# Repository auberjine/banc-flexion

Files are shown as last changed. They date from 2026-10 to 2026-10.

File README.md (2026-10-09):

# Banc de flexion 3 points auto-reactif

Poutrelle beton non arme 103 x 107 x 840, portee 750, capacite 12 kN, pour
fissuration controlee en etuve avec fibre optique et correlation d'images.

Cadre 960 x 440 x 76 mm (flancs), 35,2 kg. Flancs et platines de butee en tole
de 8 mm 42CrMo4 recuit +A, commandee avec certificat 3.1 et Re >= 430 MPa ;
pieds, crochets, plaques de traverse et plateaux du poussoir en tole de 8 mm
S355JR du commerce (seul le flanc a besoin du 42CrMo4). Tout est parametrique : une cote
se change dans `params.py`, et `make.py` refait le 3D, les DXF, les plans et la
notice. Indice B du 05/10/2026.

## Ce qu'il y a dans `out/`

| dossier | contenu |
|---|---|
| `banc_3d.html` | visionneuse 3D autonome, double-clic, aucune installation |
| `fcstd/banc.FCStd` | assemblage FreeCAD, une piece par objet |
| `step/*.step` | geometrie exacte, une piece par fichier, plus l'assemblage |
| `stl/*.stl` | maillages ; `*_montes.stl` contient tous les exemplaires places |
| `dxf/*.dxf` | profils de DECOUPE, contours fermes, arcs exacts ; la traverse y est au brut (surepaisseur a fraiser) |
| `dxf/tole_*.dxf` | tous les exemplaires d'une epaisseur et d'une nuance, ranges en etageres de 3000 mm de large au plus : controle de quantites, pas une imbrication |
| `dxf/*_EN_ATTENTE.dxf` | pieces a NE PAS decouper encore, si `ETUVE_CONFIRMEE` est faux (aucune depuis le 05/10/2026 : largeur de 538 confirmee) |
| `dxf/LISTE.txt` | fichiers, epaisseur, nuance, quantite et statut ; signification des calques |
| `plans/*.svg` | une feuille A3 cotee PAR PIECE fabriquee (`<repere>_<piece>.svg`, cartouche a son repere), plus l'ensemble (00) et le montage de la chape (07m) |
| `plans/plans.pdf` | les memes feuilles en un seul PDF, dans l'ordre des reperes |
| `plans/pdf/*.pdf` | un PDF par feuille, au nom de la feuille (`pdf_feuilles.py`, lance par `make.py`) |
| `masses.json` | masse, volume, matiere et brut de chaque piece |
| `fem_flanc.json` | resultat du calcul elements finis du flanc |
| `flambement3.json` | flambement hors plan, mode symetrique (le facteur a retenir) |
| `iso.json` | projection isometrique de l'assemblage, utilisee par les plans |

`export_dxf.py` vide `out/dxf` avant d'exporter et `build_freecad.py` vide
`out/step` et `out/stl` : aucun fichier d'une generation precedente n'y survit.

Les documents de tete sont `SPEC.md` (engendre, ne pas editer a la main),
`NOMENCLATURE.md` (engendree : commande, visserie, ordre de montage, changement
d'eprouvette) et `DEBOUT.md` (acces a la vis en position verticale et ce que
cette position impose). `SUITE.md` est un HISTORIQUE : la revue du 11/09 et la
suite qui lui a ete donnee.

## Reconstruire

```
python make.py
```

Enchaine le controle des cotes et des ligaments de percage, le modele 3D
FreeCAD (STEP, STL, masses, projection), les DXF, les plans et leur controle de
lisibilite, le PDF des planches, la visionneuse, la nomenclature, la
specification et le controle d'interference ; il termine par le nombre
d'etapes en echec, qui doit etre 0. Il faut Python 3 avec Pillow et openpyxl, FreeCAD 1.0
(`freecadcmd`) et un navigateur Chromium sans interface (Edge, Chrome ou
Chromium) pour le PDF. `outils.py` les trouve, sous Windows comme sous Linux :
variable d'environnement `BANC_FREECAD`, `BANC_CCX` ou `BANC_NAVIGATEUR`
d'abord, puis l'emplacement Windows habituel, puis le PATH.

Avant de lancer une decoupe : mesurer SEPAREMENT les deux toles livrees,
regler `EP_TOLE_REELLE_42` (42CrMo4) et `EP_TOLE_REELLE_S355` (S355JR) dans
`params.py` et regenerer les DXF. Chaque decoupe suit la tole qu'elle RECOIT :
S355 pour les encoches a mi-bois et la mortaise de traverse du flanc et les
fentes de calage du pied ; 42CrMo4 pour les encoches et nodes du pied et les
rainures des patins. Le 3D et le calcul restent a la cote nominale.

Pour refaire seulement les plans et leur PDF (make.py le fait deja) :

```
python plans.py
"C:/Program Files (x86)/Microsoft/Edge/Application/msedge.exe" --headless --no-pdf-header-footer --print-to-pdf=out/plans/plans.pdf out/plans/plans.html
```

Sous Linux : `chromium --headless --no-sandbox --no-pdf-header-footer
--print-to-pdf=out/plans/plans.pdf out/plans/plans.html`. Pour relire les
planches a l'oeil, `python rendu_planches.py` les rend en PNG dans `out/rendus/`.

Pour le calcul elements finis, en deux temps parce qu'il dure plusieurs minutes :

```
freecadcmd fem_flanc.py        (sous Windows : "C:/Program Files/FreeCAD 1.0/bin/freecadcmd.exe")
python fem_run.py
```

Le premier maille et ecrit le fichier CalculiX, le second y injecte la charge
nodale, lance le solveur et depouille le `.frd`.

## Les fichiers source

| fichier | role |
|---|---|
| `params.py` | toutes les cotes, la loi des rondelles Belleville, les calculs (Hertz, coin, filet, platines, tenons, boulonnerie) et les verifications |
| `geom2d.py` | geometrie 2D : contours, conges, bossages, gorges, lumieres |
| `parts.py` | profil de chaque piece et nomenclature du modele : matiere, brut, notes d'operations, pieces du commerce |
| `build_freecad.py` | construction 3D, exports STEP / STL, masses |
| `export_dxf.py` | DXF de decoupe, sans FreeCAD : la liste des pieces plates vient de `parts.all_parts()`, les pieces du commerce n'en ont pas |
| `dxf.py` | ecriture DXF R12 |
| `draw.py` | primitives de dessin technique : vues, cotes, cartouche (indice et date) |
| `plans.py` | les feuilles de plan, une par piece ; `draw.Sheet.fin_piece()` recentre chaque dessin au-dessus des notes |
| `viewer3d.py` | visionneuse 3D autonome : maillages ET three.js (`vendor/three.min.js`, r160) embarques dans `out/banc_3d.html`, qui s ouvre sans reseau |
| `spec.py` | engendre `SPEC.md` depuis le modele |
| `nomenclature.py` | engendre `NOMENCLATURE.md` |
| `nomenclature_xlsx.py` | engendre `out/NOMENCLATURE.xlsx` depuis `NOMENCLATURE.md` (un onglet par tableau, montage ; masses totales en formules) |
| `fem_flanc.py`, `fem_run.py` | calcul elements finis du flanc |
| `fem_balayage.py` | balaye un parametre par le calcul EF (remaille, resout, restaure) ; resultat dans `out/balayage_<param>.json` |
| | `fem_run` refuse un `.inp` deja charge, et ne charge que l arete DROITE |
| | maille de 4,5 mm : a 6 mm l angle d appui variait de 149 a 164 MPa d un calcul a l autre ; a 4,5 mm il converge aux deux appuis. `BANC_MAILLE=<mm>` impose une autre taille sans toucher au fichier |
| | le mode rigide en x est bloque sur UN SOMMET : bloquer une face epingle tous ses noeuds et raidit la tole (197 puis 145 MPa d artefacts au bord de la face) |
| | tole de 8 mm en 42CrMo4 recuit (Re 430, 390 a chaud) : flanc a 213 MPa a l appui (187 a l autre appui de cette piece symetrique : bruit de maillage), 2,02 a froid et 1,83 a 150 C, contre 1,91 a chaud pour le 10 mm S355 ; cadre de 35,2 kg au lieu de 44,5 ; repli EP_FLANC = 10 en S355 ou S460 |
| `fem_flambement.py` | flambement hors plan du flanc (CalculiX *BUCKLE, maille 9 mm), bornes : diaphragmes seuls (pieds, poutrelle ; les tubes negliges) et tubes tenus en z (mode antisymetrique, 31,9 le 18/09, avant les entretoises de chape et de sommet). `--seul x:z ...` essaie des appuis supplementaires |
| `fem_flamb3.py` | le facteur A RETENIR : mode symetrique (les deux flancs penchent ensemble), chaque tube est un ressort de rotation 6EI/L sur sa couronne serree. 13,7 couche avec les six entretoises d'origine, 33,1 avec les deux de chape, 39,0 couche et 39,1 debout avec celle du sommet (9 en tout) ; 38,2 / 38,3 avec les tubes 20 x 2 retenus le 06/10. Une plaque de 600 au dessus ne le porte qu'a 41,9 : inutile |
| `verif_interference.py` | controle d interference sur l assemblage, et des CONTACTS obligatoires |
| `verif_percages.py` | ligaments : chaque percage face aux autres et au contour ; largeur des fentes et des encoches ouvertes du contour |
| `verif_plans.py` | planches : textes superposes, hors feuille ou traverses par un trait (traits fins compris, boite orientee) ; chaque piece nommee sur une planche |
| `pdf_feuilles.py` | decoupe `plans.pdf` en un PDF par feuille dans `out/plans/pdf/` (pypdf) |
| `rendu_planches.py` | rend les planches en PNG (`out/rendus/`) pour les relire a l'oeil |
| `outils.py` | chemins des outils externes (FreeCAD, CalculiX, navigateur), Windows et Linux ; empreinte du modele et date des resultats |

`params.py` porte une fonction `verifie()` qui controle l'empilement vertical,
la course de la pile et du coin, la butee, le contact de Hertz, la place du
bossage sous le patin, la tete de charge, la chape, la boulonnerie M10 (ecrou
sur le filet, bout qui depasse), les bruts d'usinage et l'etuve (douille, pieds,
crochets). `python params.py` l'execute et affiche le bilan.

## Points de conception a ne pas defaire

- **Les flancs sont rentres sous les plats colles.** C'est ce qui degage
  entierement la face laterale de la poutrelle pour la camera. Un flanc au ras
  de la face ne porterait rien.
- **Le contact a lieu au fond de la rainure du patin**, 1,5 mm au dessus de sa
  face inferieure. Tout l'empilement en decoule.
- **Le bossage est un balancier, pas un galet.** Il laisse tourner la poutrelle
  mais n'absorbe pas le recul de 0,06 mm de la fibre basse, qui passe en
  frottement.
- **Le bossage ne porte que sur 6,4 mm** : l'epaisseur du flanc moins ses deux
  aretes cassees. Hertz y vaut 339 MPa, a comparer a 1,6 Re a chaud du corps le
  plus mou, le patin S355JR (480 MPa) : coefficient 1,42.
- **Le bas de la lumiere est une butee de course.** Il interdit d'ecraser la
  pile a plat et plafonne l'effort a 14,4 kN.
- **Le conge R22 au raccordement membrure basse / montant n'est pas le
  levier.** Le point chaud est dans la membrure basse sous le montant, pas sur
  l'arc : un balayage EF de R10 a R26 (16/09/2026, sur le flanc de 10 mm S355
  de l'epoque) donne 151 a 160 MPa sans tendance, du bruit de maillage.
- **Les patins se collent en place**, cadre monte, sous 0,5 kN de precharge.
  C'est l'epoxy qui rattrape l'hyperstaticite des quatre contacts. Colle sur la
  face superieure seulement : la rainure reste seche sur le bossage, qui doit
  basculer. Patins, plats et patin de charge partent avec la poutrelle : un jeu
  par eprouvette.
- **La vis de commande ne bouge pas.** Vis H M16 x 160 ISO 4017 filetee
  jusqu'a la tete : elle tourne en place, retenue axialement dans la chape, et
  c'est le coin qui porte le taraudage et avance. Sa tete reste donc toujours a
  y 137,5, ou une douille l'atteint. Une douille seulement : les bouts des vis
  de chape, a y 160, arretent une cle plate.
- **La commande est normale aux flancs.** Un coin d'acier C45 a 12 degres,
  garni de deux plaques de bronze usinees, coulisse entre le dessous PLAT de
  la traverse et le dessus incline du coulisseau. Le sens des faces est
  essentiel : c'est lui qui fait que le coin ne se deplace que selon y et que
  l'axe de la vis reste fixe. Voir `DEBOUT.md`.
- **Le noeud fait 65 mm de demi-largeur** et porte quatre ouvertures : la fente
  du coin au centre, les deux lumieres de guidage a x = +/- 44 et, plus haut,
  la mortaise de traverse ; les deux trous
  des vis de chape sont au dessus, a x = +/- 52. C'est la zone la plus
  sollicitee apres les appuis. Ne pas y ajouter d'ouverture : il reste 14 mm de
  ligament du cote du bord du noeud et 15 du cote de la fente.
- **Le coin est au repos bout mince affleurant le coulisseau, pas centre.**
  C'est la seule position qui garde le contact sur toute la largeur du
  coulisseau d'un bout a l'autre de la course. Le centrer ferait glisser le
  coin a moitie dehors en fin de course, et la tete basculerait sur la pile.
  C'est aussi ce qui fixe la profondeur de la chape. Voir `DEBOUT.md`.
- **Le dessus du coulisseau est incline sur TOUTE sa section.** La piece fait
  donc 36,2 de haut et non 30 : 30 est l'epaisseur au milieu. Les bruts du
  coulisseau et du coin se calculent sur la boite englobante de la piece finie
  (`parts.bruts_usinage`).
- **Le bout EPAIS du coin est du cote oppose a la chape.** Le coin avance donc
  vers elle en chargeant. La face inclinee le repousse vers son bout epais : le
  filet tire la tige vers l'INTERIEUR du cadre, et sa tete appuie sur la FACE
  EXTERIEURE des platines, a travers deux rondelles trempees. Monte a
  l'envers, la tige serait tiree hors de son alesage et ne pousserait rien :
  c'est le seul sens qui marche, et `verifie()` le controle.
- **Le jeu en largeur de la mortaise vaut DEUX FOIS le rayon de ses conges.**
  L'arete portante droite fait alors exactement la largeur du paquet de tenons.
  Le paquet cumule six fois la tolerance d'epaisseur de tole : la mortaise est
  taillee sur la tole S355 mesuree des plaques (`EP_TOLE_REELLE_S355`), pas sur
  la cote nominale.
- **Les coins de la mortaise sont des CONGES, pas des degagements d'angle.** Un
  os de chien ne se justifie que si la piece conjuguee doit porter dans l'angle.
  Ici le paquet a 2 mm de jeu par cote, et le degagement creusait une entaille
  au bout de la ligne d'appui : 209 MPa au calcul EF contre 130 (flanc de 10).
- **Les pieds de tenon portent un DEGAGEMENT, jamais un conge** -- traverse
  comme coulisseau. Un conge a un angle rentrant ajoute de la matiere dans
  l'angle : il deborde de l'epaulement et vient mordre la face du flanc.
  `geom2d.relief_ll()` fait cela, `Contour.add(..., relief=True)` l'appelle.
- **`COULISSEAU_E` n'est PAS `POUSSOIR_H`.** Depuis que le poussoir est un
  empilage de tole, ce sont deux cotes sans rapport. Les confondre dans
  `f_coulisseau` a laisse 5,9 mm de jeu entre le coin et le coulisseau pendant
  deux versions : la chaine d'effort etait ouverte dans le modele et aucun
  controle ne bronchait, un jeu n'etant pas une interference.
- **`verif_interference.py` verifie aussi les CONTACTS obligatoires.** La liste
  `CONTACTS` suit l'effort du coin jusqu'aux appuis ; c'est elle qui garantit
  que la chaine est fermee. Y ajouter tout nouveau maillon.
- **L'epaisseur du coulisseau ne tient pas a la contrainte** (5,2 MPa de
  compression pure) mais a deux details : 5 mm de matiere au dessus des
  taraudages de guide du cote MINCE de la pente, et un chapeau au dessus de
  l'alesage du tourillon. `verifie()` controle les deux.
- **La graduation de charge se lit sur le HAUT DE TETE de guide**, pas sur le
  dessus du coulisseau, invisible entre les flancs. La tangente superieure du
  cylindre se lit comme une bulle de niveau. Elle n'est gravee que d'un cote de
  la lumiere : face gravee de chaque flanc montee a l'exterieur.
- **Le coulisseau est guide par les TETES de quatre CHC M8 x 12 ISO 4762**,
  tete lisse, vissees apres coup au travers des lumieres. Un cylindre sur un
  plan porte sur une ligne : il ne peut pas se coincer en biais et il encaisse
  les defauts angulaires. Ne pas revenir a des tenons prismatiques, et ne pas
  mettre de vis a tete fraisee.
- **La tete de CHC M8 fait 13 x 8** : le 8 est exactement l'epaisseur du
  flanc. C'est ce qui rend le montage possible, `verifie()` le controle. La
  longueur d'une CHC se compte SOUS la tete : les 12 mm entrent tout entiers
  dans le taraudage de 16. Une x 20 y talonnait et laissait la tete hors de sa
  face.
- **On visse les guides APRES avoir ferme le cadre.** C'est tout l'interet :
  plus de tenons a engager a l'aveugle en presentant le second flanc.
- **Le chant du bas des plaques de traverse se fraise EN PAQUET**, plaques
  serrees sur leur tirant et alignees sur les faces hautes des tenons. C'est le
  plan de glissement du coin : une plaque en saillie de 0,1 mm deviendrait une
  charge lineique sur le bronze. Le DXF porte 1 mm de surepaisseur sur ce chant.
- **Les pieces de tole n'ont AUCUN chanfrein au modele** (09/10/2026) :
  aretes ebavurees seulement. Un STEP a aretes vives passe mieux dans les
  analyseurs des sites de decoupe. Les calculs gardent 0,8 non portant a
  chaque bord (`CHANFREIN`) : bossage, plaque de bronze sous la traverse,
  tenons.
- **Les trois plateaux du poussoir sont PERCES** : c'est le patin de charge
  colle qui fait fond sous le tourillon. `verifie()` exige ALESAGE_P == POUSSOIR_H.
  Ils sont serres en un bloc par deux vis H M6 x 35, TETE EN DESSOUS : sous le
  plateau bas il n'y a que les 10 du patin au sommet du bombe jusqu'a la
  poutrelle, une tete de 4 y tient, un ecrou non. Le patin de charge, sans
  trou, est raccourci selon x (PATIN_CHARGE_L, tire de POUSSOIR_VIS_X) pour
  laisser passer les tetes ; `controle_vis_poussoir()` en verifie les gardes.
  Le bloc n'est pas localise sur le patin : le tourillon le centre.
- **La butee de vis est POUSSEE, pas tiree.** C'est une consequence du sens de
  montage du coin, et c'est ce qui permet de la faire en tole : deux platines
  de 8 sur deux entretoises tubulaires, en compression. Si l'on remontait le
  coin a l'envers, il faudrait revenir a une chape usinee.
- **Ecrous autofreines TOUT METAL (ISO 7042)** sur la visserie M10 du cadre :
  une bague polyamide flue vers 120 C et ne freine plus dans l'etuve. Toutes
  les longueurs de vis sont controlees par `verifie()` (`params.boulonnerie`).
- **`verif_percages.py` fait partie de `make.py`.** Il refuse tout ligament
  inferieur a 0,8 fois l'epaisseur, et toute fente ou encoche du contour plus
  etroite que la demi-epaisseur. C'est lui qui a trouve l'entretoise de coin
  centree sur l'arete du flanc et l'ajour qui recoupait un trou de pied.

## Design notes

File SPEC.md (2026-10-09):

# Banc de flexion 3 points - specification

Indice B du 05/10/2026. Fichier engendre par `spec.py` a partir de `params.py`,
du calcul elements finis et du modele 3D. Ne pas le modifier a la main.

## 1. Objet

Fissuration controlee d'une poutrelle beton non arme instrumentee fibre
optique, en etuve jusqu'a 150 degres C, avec correlation d'images sur une
face laterale. Le cadre est auto-reactif : aucune reaction exterieure. Il
travaille COUCHE sur la paillasse et DEBOUT, sur son about, dans l'etuve
(voir `DEBOUT.md`).

## 2. Eprouvette et renfort

| grandeur | valeur |
|---|---|
| Poutrelle | 103 x 107 x 840 mm, beton non arme |
| Plats de renfort colles | 2 x 20 x 2 x 840, feuillard S235 du commerce, a y = +/- 34 (axe des flancs) |
| Colle | epoxy haute temperature (Duralco 4420) |
| Axe neutre de la section homogeneisee | 50.86 mm au dessus de la face inferieure |
| Inertie homogeneisee | 1.21e+07 mm4 |
| Effort a la fissuration (beton a 4 MPa) | 5.07 kN |
| Fleche a la fissuration | 0.123 mm |

Le renfort rend la fissuration progressive et pilote l'ouverture. Il
descend l'axe neutre de 2.6 mm par rapport au beton nu.

Les deux plats, les quatre patins d'appui et le patin de charge sont colles
sur la poutrelle et partent avec elle : il en faut un jeu par eprouvette.

## 3. Chargement

| grandeur | valeur |
|---|---|
| Schema | 3 points, portee 750 mm |
| Charge de dimensionnement du cadre | 12 kN |
| Commande | coin d'acier C45 a 12 deg garni de deux plaques de bronze usinees, vis H M16 pas 2.0 filetee jusqu a la tete, normale aux flancs |
| Pile de rondelles | 12 x EN 16983 A50 (ex-DIN 2093) en 51CrV4 (1.8159) (50 x 25.4 x 3.0), montees tete-beche |
| Hauteur libre de la pile | 51.6 mm |
| Effort de la pile a plat | 18.5 kN |
| Course totale | 15.6 mm |
| Ecrasement a 12 kN | 9.65 mm (raideur secante 1243 N/mm) |
| Butee de course en bas de lumiere | 11.8 mm, plafonne l'effort a 14.4 kN |
| Rattrapage d'empilement | 2.4 mm de course en reserve au dela des 12 kN (2 exiges) ; cales de 1 et 2 mm, D50 / D26, entre poussoir et pile |
| Precharge de collage, 0,5 kN | 0.36 mm de pile, 1.68 mm de coin, 0.84 tour de vis apres le contact |

La loi des rondelles Belleville n'est pas lineaire. Graduation gravee :

| charge | descente du coulisseau |
|---|---|
| 2 kN | 1.45 mm |
| 4 kN | 2.97 mm |
| 6 kN | 4.55 mm |
| 8 kN | 6.19 mm |
| 10 kN | 7.89 mm |
| 12 kN | 9.65 mm |

Cette lecture est un indicateur a quelques pour cent pres : elle englobe la
souplesse propre du cadre (0.335 mm a 12 kN) et la fleche de la poutre.
La mesure de reference est la fibre collee sur la membrure haute.

## 4. Appuis

Les flancs sont RENTRES sous les plats de renfort : ils portent dessous, et
la face laterale de la poutrelle reste entierement degagee pour la camera.

| poste | cote |
|---|---|
| Largeur de la poutrelle | 103 |
| Debord de la poutrelle de chaque cote | 13.5 |
| Epaisseur d'un flanc | 8 |
| Ecart interieur entre flancs | 60 (impose par les rondelles 50) |
| Largeur hors tout des flancs | 76 |
| Face inferieure libre au centre | 48 (passage du cable) |

Le contact se fait au FOND de la rainure du patin, 1.5 mm au dessus de sa
face inferieure.

| grandeur | valeur |
|---|---|
| Patins d'appui | 90 x 20 x 10, S355JR, colles en place |
| Rainure de guidage | 9.5 x 1.5, fraisee apres decoupe, jeu 0.75 par cote sur la tole reelle du flanc (EP_TOLE_REELLE_42) |
| Bossage | R150, relief 3.5, largeur totale 66.6 |
| Pression de Hertz a 12 kN | 339 MPa sur 6.4 mm portants (flanc de 8 moins 0.8 a chaque bord, ebavure, non compte) |
| Limite au contact a 150 degres C | 480 MPa, 1,6 Re a chaud du corps le plus mou (le patin S355JR) ; coefficient 1.42 |
| Pression sur le beton sous un patin | 1.67 MPa |
| Bras contact - axe neutre | 61.36 mm |

Le bossage est un BALANCIER, pas un galet. Il donne une ligne de contact
nette et laisse tourner la poutrelle, mais il n'absorbe pas le recul de
0.060 mm de la fibre basse a la fissuration, qui passe en frottement et
coute quelques pour cent sur le moment. Pour le supprimer il faudrait un
vrai galet libre sur une des deux lignes d'appui.

Les patins sont colles sur le plat par leur face SUPERIEURE seulement : la
rainure reste seche sur le bossage, qui doit pouvoir basculer.

## 5. Empilement vertical

z = 0 au bord inferieur du flanc.

| z | element |
|---|---|
| 40.0 | dessus de la membrure basse |
| 42.0 | dessous du patin d'appui |
| 43.5 | sommet du bossage, fond de rainure, point de contact |
| 52.0 | dessous du plat de renfort |
| 54.0 | face inferieure de la poutrelle |
| 161.0 | face superieure de la poutrelle |
| 171.0 | dessus du patin de charge |
| 195.0 | dessus du poussoir |
| 246.6 | dessous du coulisseau, pile libre |
| 236.9 | dessous du coulisseau a 12 kN |
| 276.6 | dessus du coulisseau, pile libre |
| 325.7 | dessous de la traverse a tenons, plan de glissement du coin |
| 420.0 | dessous de la membrure haute |
| 440.0 | hors tout |

Encombrement des flancs 960 x 440 x 76 mm. Selon y, le banc va de -85.5
(coin recule) a +160 (bout des vis de chape), soit 245.5 mm ; les pieds font 518.4.
Etuve 538 x 528.4 x 1400 mm (largeur x profondeur x hauteur ; largeur confirmee, profondeur = pieds + 5 de chaque cote, hauteur a confirmer) : le cadre y travaille DEBOUT sur son
about, pose par deux pieds en V sur quatre crochets pendus aux parois ; sur
la paillasse il travaille couche sur deux pieds. Voir `DEBOUT.md`.

## 6. Flanc en treillis

Le moment est triangulaire et la profondeur du treillis suit, donc l'effort
dans la membrure haute est constant sur toute sa longueur.

| membre | section | valeur |
|---|---|---|
| Membrure haute | 20 x 8 | 7.58 kN de traction, 47.4 MPa |
| Bielles | 35 x 8, pente 17.97 degres | compression |
| Montants | 45 x 8 | traction |
| Membrure basse | 40 x 8 | moment constant de 180 N.m entre appuis |
| Profondeur du treillis | 148.4 mm | |

Calcul elements finis CalculiX, 259107 noeuds, elements du second ordre,
charge de 6000 N au noeud, appuis glissants sur les deux bossages :

| grandeur | valeur |
|---|---|
| von Mises maxi | 213 MPa |
| Coefficient a froid, 42CrMo4 +A (Re 430) | 2.02 |
| Coefficient a 150 degres C (Re 390) | 1.83 |
| Fleche du flanc | 0.335 mm |
| Flambement hors plan, mode symetrique (fem_flamb3, 05/10/2026) | facteur 38.2 couche, 38.3 debout, avec les 9 entretoises |
| Flambement, flancs en sens contraire (fem_flambement, 18/09/2026) | facteur 31.9 au moins : calcul fait avant les entretoises de chape et de sommet, qui ne peuvent que le relever |

Points les plus charges :

| x | z | von Mises | zone |
|---|---|---|---|
| -420 | 30 | 213 MPa | membrure basse sous le montant, cote appui ; encoche de pied du coin voisine |
| 420 | 30 | 187 MPa | membrure basse sous le montant, cote appui ; encoche de pied du coin voisine |
| -30 | 390 | 187 MPa | angle de la mortaise de traverse, arete ou portent les tenons |
| -390 | 30 | 130 MPa | console d'appui sous le bossage |
| 390 | 30 | 125 MPa | console d'appui sous le bossage |
| 30 | 270 | 103 MPa | ligament entre la fente du coin et la lumiere |
| -30 | 270 | 103 MPa | ligament entre la fente du coin et la lumiere |
| -60 | 240 | 90 MPa | angle bas du noeud |

La piece est symetrique, le calcul donne pourtant 213 MPa d'un cote et 187
de l'autre : c'est l'ordre de grandeur du bruit de maillage a l'appui, et
l'on retient la plus forte valeur.

Le point chaud est dans la membrure basse sous le montant, pas sur l'arc
du conge R22 du raccordement membrure basse / montant.
Un balayage du rayon de R10 a R26 (fem_balayage.py, 16/09/2026, sur le flanc de
l'epoque) donne 151 a 160 MPa sans tendance : c'est du bruit de maillage,
le rayon n'est pas le levier.

NUANCE ET EPAISSEUR. Le flanc est en tole de 8 mm 42CrMo4, etat recuit +A
(Re 430, 390 a 150 C). L'EN 10083-3 ne garantit a l'etat +A qu'une durete
maximale, pas de limite elastique : toute la marge du flanc repose sur Re,
qui est donc EXIGE a la commande -- 42CrMo4 recuit +A, tole 8 mm : certificat 3.1 EN 10204 avec essai de traction, Re >= 430 MPa a 20 C.
Le flanc travaille a 213 MPa a l'appui : 2.02 de coefficient a froid, 1.83 a
150 C, contre 1,91 a chaud pour le cadre precedent en 10 mm S355 (157 MPa)
et 34.5 kg de cadre au lieu de 44,5.
Si la tole de 8 en 42CrMo4 manque, le repli est le 10 mm S355 ou S460 :
EP_FLANC = 10 et tout suit.

DEUX TOLES DE 8 (decision du 05/10/2026). Seul le flanc a besoin du 42CrMo4 :

| piece | nuance | pourquoi |
|---|---|---|
| Flanc | 42CrMo4 +A, tole 8 mm, cert. 3.1, Re >= 430 | 213 MPa a l'EF : toute la marge du cadre |
| Platine de butee | 42CrMo4 +A, tole 8 mm, cert. 3.1, Re >= 430 | 130 MPa : en S355JR elle n'aurait plus que 2.3 a 150 C, sous le seuil de 2,5 de `verifie()` ; imbriquee dans les chutes de la tole des flancs |
| Plaques de traverse | S355JR, tole 8 mm, cert. 2.2 | 8 MPa en flexion, 26 au matage ; chant fraise frottant sur la plaque bronze-graphite, acceptable a 8 MPa et a cette vitesse |
| Crochets, pieds, plateaux du poussoir | S355JR, tole 8 mm, cert. 2.2 | une quinzaine de MPa au crochet, quelques MPa ailleurs |

Les deux toles se mesurent SEPAREMENT (EP_TOLE_REELLE_42, EP_TOLE_REELLE_S355) :
chaque fente, encoche ou mortaise suit la tole qu'elle RECOIT (voir le
paragraphe des points ouverts).

## 7. Tete de charge

Chaine d'effort, de haut en bas : traverse a tenons portee par la mortaise
des flancs, coin de commande qui glisse sous elle sur ses plaques de bronze,
coulisseau guide par les tetes de quatre CHC M8 dans les lumieres, pile de
rondelles sur tourillon colle dans le coulisseau, poussoir, patin de charge colle. La
reaction remonte par les montants et les bielles dans la membrure haute,
qui travaille en traction.

| piece | remarque |
|---|---|
| Traverse | 6 plaques de tole 8, tenons dans la mortaise des flancs, chant du bas fraise en paquet |
| Coulisseau | S355JR, dessus incline sur TOUTE sa section ; un bloc, sans tenon |
| Guidage | 4 tetes de CHC M8 x 12 ISO 4762, tete lisse, diametre 13, dans des lumieres de 14 ; taraudages M8 prof. 16 |
| Poussoir | 3 plateaux de tole 8 perces, serres en un bloc par 2 vis H M6 x 35 ISO 4017 8.8 a +/- 38, tete en dessous, rondelle et ecrou ISO 7042 au dessus, 8 N.m ; le patin de charge fait fond |
| Vis du poussoir, tete en dessous | sous le plateau bas il n'y a que les 10 du patin au sommet du bombe jusqu'a la poutrelle : un ecrou, sa rondelle et le bout de vis n'y tiennent pas, une tete de 4 si (6 de garde) ; angle de tete a 3.5 du bout du patin, angle d'ecrou a 7.5 de la pile |
| Patin de charge | dessus BOMBE R1000 (0.42 de chute aux bords), dessous plat colle : le poussoir porte sur une ligne transversale, Hertz 88 MPa a 12 kN, coefficient 5.4 |
| Alignement du poussoir | les 3 plateaux sont visses en bloc ; le bloc n'est pas localise sur le patin : c'est le tourillon, colle dans le coulisseau, qui le centre (jeu 0.4 dans l'alesage 25.4 des plateaux), et le patin de charge est colle centre au trace |
| Patin de charge, encombrement | 58 x 100 x 10 sans trou : sa longueur selon x laisse passer les tetes des vis du poussoir ; 2.07 MPa sur le beton a 12 kN |
| Tourillon | C45+C, rond etire 25 h9 x 79.5 non repris, COLLE au fond du coulisseau (Loctite 648 (tient 175 C), alesage 25 H8 degraisse) ; dans le poussoir : 7.9 au repos, 4.9 avec les cales, 4.3 de garde au dessus du patin a la butee |
| Vis de commande | vis H M16 x 160 ISO 4017 8.8 brute, filetee jusqu a la tete, immobile axialement dans la chape, le coin est son ecrou |
| Butee de course | bas de la lumiere, interdit l'aplatissement de la pile |

## 7 bis. Commande par coin

L'etuve fait 538 x 528.4 x 1400 (largeur x profondeur x hauteur, largeur confirmee) et n'offre aucun passage de paroi
utilisable. Le cadre y est debout : un axe de vis dans le plan des flancs
regarderait une paroi a 49 mm, inaccessible. La commande est donc NORMALE
AUX FLANCS. Un coin en ACIER, qui porte le taraudage, coulisse selon y entre
le dessous plat de la traverse et le dessus du coulisseau taille au meme
angle. Le coin ne se deplace que selon y : son dessus reste plaque sous la
traverse, donc l'axe de la vis est fixe.

| grandeur | valeur |
|---|---|
| Angle | 12 degres |
| Coin | acier C45, 40 de large, 30.8 a 55.2 d'epaisseur, 114.5 de long |
| Plaques de frottement | 2 plaques usinees en CuSn12-C, 38 x 102 (dessus) et 38 x 104 (dessous) x 6, sous pate graphite haute temperature, 0.41 kg en tout |
| Course utile | 56.5 mm selon y |
| Position de repos | bout epais a y -85.5, bout mince a y 29 |
| Sens de marche | vers la chape ; en fin de course le bout mince est a y 85.5 |
| Depassement hors cadre | 47.5 mm, d'un cote au repos, de l'autre en fin de course |
| Vis | M16 pas 2.0, taraudee dans le coin, immobile axialement |
| Effort moteur a 12 kN | 5.5 kN |
| Couple sur la vis | 14.5 N.m |
| Course par tour | 0.425 mm de coulisseau, environ 549 N |
| Pression de contact, fin de course | 7.6 MPa en haut sur 30.0 x 52.8 (joints de traverse deduits), 6.3 MPa en bas sur 38 x 50.4 ; 25 admis |
| Rendement | 46 pour cent |

Le coin n'est autobloquant que si le frottement de ses deux faces depasse
0.106 (tan a / 2) : avec le bronze graphite a chaud (0.12) on y est a peine,
on ne compte donc pas dessus. C'est la vis M16 qui tient la charge, son
angle d'helice etant tres inferieur a l'angle de frottement. Le filet est
de l'acier sur acier monte a la pate cuivre, et le cas dangereux est le
frottement BAS : a 0.08, helice 2.48 degres contre 5.28 degres de frottement
apparent, marge x2.13.

C'est pourquoi le filet reste METRIQUE a pas de 2 et non trapezoidal.
Au meme frottement de 0.08, un Tr16x4 tomberait a une marge de 0.91 :
il serait REVERSIBLE, et il doublerait le pas de charge a 1099 N par tour.
A pas egal, le profil trapezoidal ne gagne rien non plus : sa hauteur de
recouvrement vaut 0,5 P contre 0,541 P pour le metrique, soit MOINS de
flanc portant. Les flancs travaillent a 9.2 MPa, engagement plafonne a
1,5 d, pour 12 admis sur un taraudage C45 et une vis 8.8 en manoeuvre lente.

Le filet est TARAUDE DIRECTEMENT DANS L'ACIER du coin. Une bague-ecrou en
bronze a ete dessinee puis abandonnee : a la vitesse de manoeuvre d'un
banc a la main, ce n'est pas la vitesse qui use un filet, et le couple
vis 8.8 sur C45 brut tient sans probleme monte a la pate cuivre. La vis
est la plus dure : c'est le taraudage du coin qui s'use, et il se refait.
Il ne court que sur 80 mm et non sur toute la longueur du coin ; au dela
le percage est repris a 18, si bien que le taraud debouche dans un trou
plus grand : les copeaux s'evacuent vers l'avant et il n'y a que 5 d a
tarauder au lieu de 7. Si le filet devait un jour lacher, le lamage
d'une bague de bronze reste possible : rien ici n'est irreversible.

LE BRONZE N'EST PLUS QUE DEUX PLAQUES, TOUTES DEUX SUR LE COIN.
Un coin de bronze plein aurait demande 2,7 kg de barre, une section qu'il
faut faire debiter. Or le bronze n'est utile que sur les deux faces de
glissement : il est reporte sur deux plaques de frottement en CuSn12-C, de
simples rectangles fraises dans un plat 40 x 8 (38 x 102 et 38 x 104, ep. 6),
usines avec le reste plutot qu'achetes a part, et le coin devient un bloc d'acier C45
de 1.37 kg, usine dans un plat 70 x 45, L 120 (fini 63 x 40 x 114,5).

La basse pourrait etre posee sur la pente du coulisseau, ou elle ne ferait
que 58 de long au lieu de 104. Elle est mise sur le coin comme la
haute : le coulisseau redevient un bloc nu -- un percage et un plan a 12
degres, ni poche ni taraudage -- les deux faces d'usure sortent ensemble
avec le coin, et c'est deux fois le meme rebord a usiner. Ce que cela
coute : la plaquette basse traverse la fente du flanc avec le coin, qui
s'approfondit donc de 6.1 mm.

Aucune vis : le coin ne fait que 40 de large et le percage de la vis en
prend le milieu, il ne reste pas de quoi noyer une tete fraisee a un
ligament d'epaisseur. Chaque plaquette est prise entre DEUX REBORDS usines
dans la masse, 4.25 (dessus) et 4.43 (dessous) x 4, qui encaissent les 1.44 kN
d'entrainement dans l'axe de la vis : flexion 23.9 MPa au pied, matage du chant 18 MPa.
Elles ne sont PAS collees a l epoxy. Bronze et acier ne se dilatent pas
pareil : a 150 C la plaquette s allonge de 0.09 mm de plus que son siege,
et un joint rigide sur toute la longueur encaisserait 30 a 80 MPa de
cisaillement en bout pour 15 a 20 tenus : il fissurerait au premier
chauffage. Les rebords prenant tout l entrainement, la fixation n a plus
qu a tenir la plaquette le temps du montage : quelques points de silicone
haute temperature, 1000 fois plus souple, y suffisent -- 0.146 MPa de
cisaillement thermique dans le joint. Le CuSn12-C n'est pas autolubrifiant :
pate graphite haute temperature sur les faces de glissement, posee APRES la prise du silicone ;
rien sur les sieges, le silicone ne prend pas sur une pate.

Pied de rebord SANS degagement : conge R2, le bout d'une fraise de 4 (pas de
conge interieur sous R2 sur les pieces fraisees),
et chaque logement a 4 de plus que sa plaquette, si bien que l'angle du
bronze ne monte pas sur le conge. Et sur la face inclinee, la face interieure
du rebord est NORMALE A LA PENTE et non verticale, comme le chant de la
plaquette : dessinees verticales, elles la mordaient de 1.3 mm en bas.

Les rebords s'arretent 2 mm SOUS la surface du bronze. Aux deux bouts de
course ils passent sous la conjuguee, et s'ils affleuraient ce serait de
l'acier sur acier qu'on ferait glisser. Il en coute de la portee : la
plaquette haute porte sur 52.8 mm au lieu de 60, la basse sur 50.4 au
lieu de 58, soit 7.6 et 6.3 MPa.

Le filet reste engage sur 27.0 mm coin recule, soit 1.7 d, ce qui est
tout ce qui porte : au dela de 1,5 d, l'ecart de pas entre la vis et le
taraudage fait que les derniers filets ne prennent plus rien.

Le coin traverse les deux flancs par une fente de 44 x 71, entre les
deux lumieres de guidage reportees a x = +/- 44. Il reste alors 58 mm
de section nette dans le noeud, soit 12.9 MPa nominal pour les 6000 N par flanc.

La suppression de la vis verticale a ramene la hauteur du cadre de 480 a
440 mm : debout dans l'etuve de 538, il reste 49 mm de chaque cote, ou se
logent les pieds en V et les crochets. Elle a aussi permis de descendre le
noeud : la profondeur du treillis passe de 139,5 a 148.4 mm.

### Sens de montage du coin, et arret axial de la vis

Le bout EPAIS du coin est du cote OPPOSE a la chape : le coin avance donc
VERS elle en chargeant. C'est ce sens, et lui seul, qui rend l'arret axial
de la vis possible. L'equilibre du coin le montre : la composante selon y
de la reaction du coulisseau, plus les deux frottements, valent 5.5 kN, et
la vis doit les fournir. La face inclinee repousse le coin vers son bout
EPAIS : le filet tire donc la vis vers l'INTERIEUR du cadre, et sa tete
vient appuyer sur la FACE EXTERIEURE des platines, a travers deux rondelles
trempees graissees. Cote interieur, deux autres et deux ecrous minces ne
reprennent que l'effort de desserrage : 329 N a un frottement de 0.12, quand
le coin est autobloquant ; en dessous de 0.106 la charge le chasse d'elle-meme
et ils ne voient rien.

Monte a l'envers, le coin s'eloignerait de la chape en chargeant : la vis
serait tiree hors de son alesage et ne pousserait rien. Il faudrait alors
loger la butee entre les platines et le bout du coin, ou elle ne tient
pas. Le controle des cotes refuse ce sens.

### Position de repos du coin

Le coin est dessine au repos bout mince AFFLEURANT le bord du coulisseau,
et non centre sur lui. C'est la seule position qui garde le contact sur
toute la largeur du coulisseau d'un bout a l'autre de la course. Centre au
repos, le coin aurait glisse a moitie hors du coulisseau en fin de course :
appui reduit a 29 mm au lieu de 58, pression doublee, et surtout
resultante decalee de 14.5 mm, donc basculement de la tete sur la pile.
Le prix a payer est que le bout mince atteint y 85.5 en fin de course, ce
qui fixe la position de la chape de butee.

## 7 ter. Butee axiale de la vis

Le coin avance VERS la butee en chargeant et tire la vis vers l'interieur
du cadre ; la tete de la vis pousse donc la butee, et les platines, contre
le flanc : platines en flexion, entretoises en compression, aucune piece de
la butee ne travaille en traction. Il n'y a aucune raison d'usiner une chape
dans la masse. Deux platines de la MEME tole que les flancs, portees par deux
entretoises du MEME tube que le cadre, de part et d'autre de la vis, dans le
plan de son axe. Deux vis H M10 x 200 traversent platines, entretoises de
butee, LES DEUX flancs et une entretoise de cadre entre eux, tete derriere
le flanc oppose, ecrou cote platines : plus aucun taraudage dans le flanc,
et deux entretoises de plus entre les flancs. Elles ne voient que la
precharge et les 329 N de desserrage.

| grandeur | valeur |
|---|---|
| Platines | 2 x tole 8, 70 de haut au droit de l'alesage, 140 de long |
| Flexion d'une platine | 130 MPa, coefficient 3.3 a froid, 3.0 a 150 C, fleche 0.139 mm |
| Entretoises de butee | tube de precision 20 x 2, L = 71.5 +/-0,2, 24.5 MPa de COMPRESSION chacune |
| Fixation | 2 vis H M10 x 200 ISO 4014 (filetees sur 32) a x = +/- 52, z 303.7, tete et 1 rondelle derriere le flanc oppose, 4 rondelles + 2 ecrous H contre-bloques cote platines |
| Serrage sous tete | 173.5 mm, filet a partir de 168 : ecrou sur le filet avec 5.5 de marge, 9.7 de depassement |
| Serrage | 25 N.m, aucun taraudage : les vis traversent les deux flancs |
| Butee sous la tete | 2 rondelles trempees AS 1730, pate graphite haute temperature entre elles, a plat sur la face EXTERIEURE ; frottement 0.10 compte dans le couple |
| Retenue interieure | 2 rondelles trempees AS 1730 + 2 ecrous HM M16, 18 mm, desserrage seulement |
| Tete de la vis | dessus a y 138, soit 117 mm de degagement pour la douille, cadre decentre au pire dans l'etuve de 528.4 (127 centre) |
| Manoeuvre | douille de 24 et cliquet SEULEMENT : les bouts des vis de chape (y 160) depassent la tete de manoeuvre dans son plan, une cle plate bute dessus |

Tout sort du debit deja commande : les platines nichent dans la tole de 8
des flancs, les entretoises sont coupees dans le meme tube que celles du
cadre. Rien a usiner. Les vis traversent LES DEUX flancs, avec une
entretoise de cadre entre eux : la commande se monte du cote que l'on veut,
en retournant le coin, et les deux percages servent dans les deux cas.

Une entretoise de sommet, dans l'axe a z 412, au dessus de la mortaise de
traverse : la membrure haute n'avait aucune liaison sur 500 mm et c'est la
que partait le mode de voilement symetrique. Meme tube de 60, meme vis TH
M10 x 100 que les autres entretoises de cadre. Ce n'est PAS un serrage des
flancs sur le paquet de traverse : le tube de 60 fixe l'ecart des flancs,
et les epaulements de la traverse gardent 0.4 de jeu selon y (0.2 de chaque
cote) : la traverse n'est jamais pincee.

Boulonnerie M10 du cadre, toutes longueurs controlees par `verifie()` sur la
tole reelle (EP_TOLE_REELLE_42 au travers des flancs et des platines, paquet de
traverse a TRAVERSE_LX_REEL en S355) : l'ecrou doit tomber sur le filet avec 2.5 de
marge et le bout depasser de 3 pour que le freinage soit en prise.

| boulonnerie | serrage | ecrou | depassement | marge de filet |
|---|---|---|---|---|
| vis de cadre TH M10 x 100 | 80.0 | 10 | 10.0 | - |
| vis de traverse H M10 x 100 | 52.0 | 10 | 38.0 | - |
| vis de chape H M10 x 200 | 173.5 | 16.8 | 9.7 | 5.5 |

Ecrous de cadre et de traverse : ISO 7042 classe 8, autofreine tout metal. Pas d'ecrou a bague polyamide
(ISO 7040, DIN 985) : la bague flue vers 120 C et ne freine plus a 150 C.
7 vis de cadre (4 de coin, 2 de bielle, 1 de sommet) et 2 vis de chape
serrent les 9 entretoises.

## 8. Instrumentation

| poste | valeur |
|---|---|
| Fibre sur le chant de la membrure haute | 18.8 microdeformations par kN |
| Resolution a 1 microdeformation | 53 N |
| Lecture mecanique | position du coulisseau dans la lumiere |
| Correlation d'images | face laterale degagee sur 840 x 107 mm |

Il n'y a pas de col de mesure : la membrure pleine donne deja une
resolution suffisante, et un col serait une entaille de plus.

## 9. Masses

Masses du modele 3D (out/masses.json, construit le 09/10/2026).

| piece | qte | masse unitaire | total |
|---|---|---|---|
| Flanc en treillis | 2 | 10.24 kg | 20.48 kg |
| Plaque de traverse | 6 | 0.25 kg | 1.51 kg |
| Plateau de poussoir | 3 | 0.33 kg | 0.98 kg |
| Coulisseau a tete inclinee | 1 | 1.46 kg | 1.46 kg |
| Vis de guidage CHC M8 x 12 | 4 | 0.01 kg | 0.05 kg |
| Tourillon de centrage | 1 | 0.31 kg | 0.31 kg |
| Coin de commande | 1 | 1.37 kg | 1.37 kg |
| Plaque de frottement, dessus | 1 | 0.20 kg | 0.20 kg |
| Plaque de frottement, dessous | 1 | 0.21 kg | 0.21 kg |
| Vis de commande H M16 x 160 | 1 | 0.34 kg | 0.34 kg |
| Platine de butee de la vis | 2 | 0.45 kg | 0.91 kg |
| Entretoise de butee | 2 | 0.06 kg | 0.13 kg |
| Patin d'appui rainure | 4 | 0.13 kg | 0.52 kg |
| Patin de charge | 1 | 0.45 kg | 0.45 kg |
| Plat de renfort colle | 2 | 0.26 kg | 0.53 kg |
| Entretoise tubulaire | 9 | 0.05 kg | 0.48 kg |
| Pied a mi-bois | 4 | 0.87 kg | 3.49 kg |
| Crochet d etuve | 4 | 0.17 kg | 0.69 kg |
| Pile de 12 rondelles Belleville | 1 | 0.41 kg | 0.41 kg |
| Poutrelle beton | 1 | 22.22 kg | 22.22 kg |

**Cadre complet 34.5 kg**, poutrelle 22.2 kg.

## 10. Conduite d'essai

- rampes thermiques sous 0,2 degres C par minute : avec 107 mm d'epaisseur,
  une rampe de 1 degre par minute creee deja 5 MPa d'ecart entre coeur et peau
- palier de stabilisation d'au moins 2 heures avant toute lecture
- acier nu ou phosphate, pas de zingue au dela de 200 degres C
- pate graphite ou cuivre sur le filetage de la vis, pate graphite haute temperature sur les faces
  de glissement des plaques de bronze, a refaire a chaque demontage du coin
- relaxation des rondelles de quelques pour cent au dela de 100 degres C :
  reprendre la charge a chaque palier
- revetement de la fibre a verifier : l'acrylate standard ne tient pas 150 degres C
- manoeuvre a la douille de 24 et au cliquet

## 11. Points ouverts

- **Hauteur d'etuve 1400, a confirmer.** La largeur 538 est confirmee : elle
  place la dent du crochet a 47.2 de la paroi ; pied et crochet sont a decouper.
- **Epaisseurs reelles des deux toles** : mesurer les deux toles livrees, regler EP_TOLE_REELLE_42 (42CrMo4) et EP_TOLE_REELLE_S355 (S355JR) et regenerer les DXF avant decoupe (EP_TOLE_REELLE_42 = 8 et
  EP_TOLE_REELLE_S355 = 8 pour des toles nominales de 8). Chaque decoupe suit
  la tole qu'elle RECOIT : S355 pour les encoches et la mortaise du flanc et
  les fentes de calage du pied ; 42CrMo4 pour les encoches et nodes du pied et
  les rainures des patins. Le 3D et le calcul restent a la cote nominale.
- **Calage de la poutrelle debout** : rien ne la retient selon x, devenu
  vertical, que le frottement aux appuis. Point ouvert, assume : voir
  `DEBOUT.md`, paragraphe 6.

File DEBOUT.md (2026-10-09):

# Position debout : commande normale aux flancs

Etuve 538 x 528,4 x 1400 mm utiles (largeur x profondeur x hauteur : largeur 538 entre les parois laterales ou pendent les crochets, confirmee le 05/10/2026 ; profondeur porte - fond 528,4 = pieds de 518,4 et 5 mm de chaque cote ; hauteur a confirmer), aucun passage de paroi
utilisable. La poutrelle est verticale, le cadre repose sur son about bas par
deux pieds en V, poses sur quatre crochets pendus aux parois.

| direction | cote du cadre | cote d'etuve | degagement |
|---|---|---|---|
| verticale | 960 ; 969,5 avec les pieds en V | 1400 | 430 mm en tout, partages entre dessus et dessous selon la hauteur des crochets |
| axe des 440 mm du cadre | 440 ; 447 entre les aretes de pose des pieds en V | 538 | 49 mm de chaque cote du cadre, ou se logent les pieds en V et les crochets |
| epaisseur du cadre | 76 aux flancs ; 245,5 avec le coin et la chape (y -85,5 a +160) ; pieds de 518,4 | 528,4 | 226 mm de chaque cote des flancs ; 5 aux bouts des pieds |

Toute la place est dans la direction de l'EPAISSEUR du cadre. La commande doit
donc y arriver, en traversant les flancs.

Les chiffres ci-dessous sont ceux de l'indice A (02/10/2026). Ceux qui changent
avec une cote sont aussi dans `SPEC.md` et `NOMENCLATURE.md`, qui se
regenerent : en cas d'ecart, ce sont eux qui font foi.

## 1. Pourquoi un coin, et pas autre chose

Un axe de vis dirige vers les parois laterales est inaccessible, quoi qu'on
mette au bout : il reste 50 mm, que les pieds en V et les crochets occupent
deja. Trois solutions sans mecanisme ont ete ecartees, toutes pour la meme
raison : barre, cle ou volant balaient le plan perpendiculaire a l'axe, celui
qui contient l'epaisseur du cadre, et heurtent les flancs des 30 mm de rayon
(le demi-ecart des flancs). Un volant est de toute facon limite a 60 mm de
diametre par l'ecart entre flancs, soit 6 N.m quand il en faut 9,4.

Un renvoi d'angle a roue et vis sans fin a d'abord ete monte, puis remplace par
le coin : le coin fait le meme travail avec moins de pieces et une vis en prise
directe.

## 2. Ce qui est monte

Un coin en ACIER C45, taraude M16, coulisse selon y entre le DESSOUS PLAT de la
traverse et le DESSUS du coulisseau taille au meme angle. Ses DEUX faces de
glissement portent une plaque de bronze CuSn12-C usinee.

Le sens des faces est ce qui rend le montage possible : si le coin glissait sur
une rampe fixe, il descendrait en avancant et la vis devrait suivre ce mouvement
vertical. Avec le dessus du coin plat sous la traverse, le coin ne se deplace
que selon y, et l'axe de la vis reste fixe.

| grandeur | valeur |
|---|---|
| Angle | 12 degres |
| Coin | acier C45, 40 de large, 30,8 a 55,2 d'epaisseur, 114,5 de long |
| Plaque haute | CuSn12-C usine 38 x 102 x 6, sans trou, entre deux rebords de 4,25 |
| Plaque basse | CuSn12-C usine 38 x 104 x 6, sur la pente, entre deux rebords de 4,43 |
| Taraudage | M16 sur 80 mm depuis le bout epais, passage a 18 au dela |
| Course utile | 56,5 mm selon y |
| Effort moteur a 12 kN | 5,5 kN |
| Couple sur la vis | 14,5 N.m, dont 5,7 de frottement sous la tete |
| Course par tour | 0,425 mm de coulisseau, environ 549 N |
| Pression de contact, fin de course | 7,6 MPa en haut (30 nets x 52,8), 6,2 en bas (38 x 50,6) |
| Guidage | 4 tetes de CHC M8 x 12, diametre 13, dans des lumieres de 14 |
| Rendement | 46 pour cent |

LE BRONZE N'EST PLUS QUE DEUX PLAQUES, TOUTES DEUX SUR LE COIN. Un coin de
bronze plein aurait pese 2,7 kg de barre, une section qui ne se trouve pas en
stock ; les deux plaques, de simples rectangles fraises dans du plat 40 x 8 et
usines avec le reste de la commande (07/10/2026, au lieu de plaques norelem du
commerce), en font 0,41 kg. La plaque basse pourrait etre posee sur la pente du
coulisseau, ou elle ne ferait que 58 de long au lieu de 104 ; la mettre sur le coin rend le coulisseau a l'etat de
bloc nu -- un percage et un plan a 12 degres, ni poche ni taraudage -- fait
sortir les deux faces d'usure ensemble avec le coin, et n'oblige a usiner que
deux fois le meme rebord. Ce que cela coute : la plaque basse traverse la fente
du flanc avec le coin, qui s'approfondit donc de 5,1 mm.

Le filet est taraude DIRECTEMENT DANS L'ACIER. A la vitesse de manoeuvre d'un
banc a la main, ce n'est pas la vitesse qui use un filet, et le couple tige 8.8
sur C45 brut tient monte a la pate cuivre. La tige est la plus dure : c'est le
taraudage qui s'use, et il se refait. Il ne court que sur 80 mm ; au dela le
percage est repris a 18, si bien que le taraud debouche dans un trou plus grand
et qu'il n'y a que 5 d a tarauder au lieu de 7. Si le filet devait un jour
lacher, le lamage d'une bague de bronze reste possible.

AUCUNE VIS SUR LES PLAQUES : le coin ne fait que 40 de large et le percage de
la tige en prend le milieu, il ne reste pas de quoi noyer une tete fraisee a un
ligament d'epaisseur. Chaque plaque est prise entre DEUX REBORDS usines dans la
masse, 4,25 (dessus) et 4,43 (dessous) de large pour 4 de haut, qui encaissent
les 1,44 kN d'entrainement dans l'axe de la vis : flexion 23,9 MPa au pied,
matage du chant 18 MPa. Il n'y a pas de colle structurale : une epoxy
fissurerait au premier chauffage, bronze et acier ne se dilatant pas pareil.
Quelques points de silicone haute temperature tiennent la plaque pendant le
montage ; la dilatation differentielle n'y met que 0,14 MPa de cisaillement.
Le CuSn12 n'est pas autolubrifiant : pate graphite haute temperature sur les
faces de glissement, posee APRES la prise du silicone, et rien sur les sieges,
car le silicone ne prend pas sur une pate.

Pied de rebord SANS degagement : conge R2, le bout d'une fraise de 4 (aucun
conge interieur sous R2 sur les pieces fraisees, 09/10/2026), et chaque logement a
4 mm de plus que sa plaque, si bien que l'angle du bronze ne
monte pas sur le conge. Sur la face inclinee, la face interieure du rebord est
NORMALE A LA PENTE et non verticale, comme le chant de la plaque : dessinees
verticales, elles la mordaient de 1,3 mm en bas.

Les rebords s'arretent 2 mm SOUS la surface du bronze. Aux deux bouts de course
ils passent sous la piece conjuguee, et s'ils affleuraient ce serait de l'acier
sur acier qu'on ferait glisser. Ils coutent de la portee : la plaque haute
porte sur 51,8 mm au lieu de 60, la basse sur 48,6 au lieu de 58.

Le coin n'est autobloquant que si le frottement de ses deux faces depasse
0,106 (tan 12 / 2) : avec le bronze graphite on y est a peine, on ne compte
donc pas dessus. C'est la vis M16 qui tient la charge, son angle d'helice
(2,5 degres) etant tres inferieur a l'angle de frottement, meme au frottement
bas d'un filet acier sur acier monte a la pate cuivre (0,08 : 5,3 degres,
marge x2,1).

La commande est une vis H M16 x 160 ISO 4017 filetee jusqu'a la tete (07/10/2026,
a la place d'une tige filetee coiffee de deux ecrous bloques) : la tete forgee
ne se debloque pas et ne fait que 10 de haut. Son dessus est a y 137,5. En
profondeur la chambre fait 528,4 : cadre centre, il reste 127 mm jusqu'a la
paroi ; 117 en comptant 10 de garde (5 de jeu des pieds de 518,4, plus 5 de
marge). Une douille de 24 et un cliquet y passent. Une douille SEULEMENT : les
vis de chape depassent de leur ecrou jusqu'a y 160, a 52 mm de l'axe de la vis
et dans son plan ; une cle plate posee sur la tete bute dessus a chaque tour.

## 3. Sens de montage du coin, et arret axial de la tige

Le bout **epais** du coin est du cote **oppose a la chape** : le coin avance
donc VERS elle en chargeant. Ce sens, et lui seul, rend l'arret axial de la
tige possible.

L'equilibre du coin le dit : la composante horizontale de la reaction du
coulisseau, plus les deux frottements, valent 5,5 kN, et c'est la tige qui doit
les fournir. La face inclinee repousse le coin vers son bout EPAIS : le filet
tire donc la tige vers l'**interieur** du cadre, et sa tete vient appuyer sur
la **face exterieure** des platines, a travers deux rondelles trempees
graissees. Cote interieur, deux autres rondelles trempees et deux ecrous minces ne reprennent que le
desserrage : 329 N quand le coin est autobloquant, rien en dessous.

Monte a l'envers, le coin s'eloignerait de la chape en chargeant : la tige
serait tiree hors de son alesage et ne pousserait rien. Il faudrait alors loger
la butee entre les platines et le bout du coin, ou elle ne tient pas. `params.verifie()` refuse ce sens.

## 3 bis. Position de repos du coin, et ce qu'elle impose

Le coin est monte au repos **bout mince affleurant le bord du coulisseau**, et
non centre sur lui. C'est la seule position qui garde le contact sur toute la
largeur du coulisseau d'un bout a l'autre de la course : centre au repos, le
coin aurait glisse a moitie hors du coulisseau en fin de course, avec un appui
de 29 mm au lieu de 58, une pression doublee et surtout une resultante decalee
de 14,5 mm, donc une tete qui bascule sur la pile de rondelles.

Le prix a payer est que le bout mince atteint y 85,5 en fin de course, soit
47,5 mm hors du flanc. Le bout epais sort autant de l'autre cote au repos.
C'est cette cote qui fixe la profondeur de la chape.

## 4. La butee de la vis

Le coin tire la tige vers l'interieur ; sa tete pousse la butee, donc les
platines, contre le flanc. Platines en flexion, entretoises en compression :
rien ne travaille en traction, il n'y a donc rien a usiner. Deux platines de la
meme tole de 8 que les flancs, portees par deux entretoises du meme tube que le
cadre, de part et d'autre de la vis, dans le plan de son axe.

| grandeur | valeur |
|---|---|
| Platines | 2 x tole 8, 70 de haut au droit de l'alesage, 140 de long |
| Flexion d'une platine | 130 MPa, coefficient 3,3 a froid et 3,0 a 150 C, fleche 0,14 mm |
| Entretoises | tube de precision 20 x 2, L = 71,5 +/- 0,2, **24,5 MPa de compression chacune** en service, 111 MPa sous la precharge |
| Fixation | 2 vis H M10 x 200 filetees sur 32, a x = +/- 52 dans le plan de l'axe de vis ; tete et 1 rondelle derriere le flanc oppose, 4 rondelles + 2 ecrous H ISO 4032 (8,4) contre-bloques cote platines. Empilement sous tete 173,5, filet a partir de 168 : le premier ecrou tombe sur le filet avec 5,5 de marge, la vis depasse du contre-ecrou de 9,7 |
| Serrage | 25 N.m (12,5 kN de precharge, a cause des tubes 20 x 2), aucun taraudage : les vis traversent les deux flancs et une entretoise de cadre |
| Butee sous la tete | 2 rondelles trempees AS 1730, pate graphite entre elles, a plat sur la face EXTERIEURE (une butee a aiguilles AXK 1730 jusqu'au 08/10/2026 : elle n'apportait que 5 N.m de couple en moins) |
| Retenue interieure | 2 rondelles trempees AS 1730 (17 x 30 x 1) + 2 ecrous HM : 329 N au desserrage seulement |

Quatre rondelles sous l'ecrou : l'empilement additionne quatre toles et deux
tubes coupes. Avec deux rondelles il faisait 169,5 pour un filet qui commence a
168 ; avec trois, une tole mesuree sous 7,75 faisait encore tomber la marge sous
2,5. Avec quatre, verifie() accepte toute la tolerance de livraison (7,5 a 9,2) :
l'ecrou ne vient jamais buter en fin de filet sans serrer.

Les deux percages sont dans LES DEUX flancs, et les vis les traversent tous les
deux avec une entretoise de cadre entre eux : deux entretoises de plus sans
piece de plus, et la commande se monte du cote que l'on veut en retournant le
coin.

Une entretoise de sommet, dans l'axe au dessus de la mortaise de traverse
(z 411), tient la membrure haute, qui n'avait aucune liaison sur 500 mm.
Voilement symetrique (fem_flamb3, ressorts 6EI/L) : 13,7 avec les six
entretoises d'origine, 33,1 avec les deux de chape a +/- 52, 39,0 couche et
39,1 debout avec celle du sommet ; 38,2 / 38,3 avec les tubes 20 x 2 retenus le 06/10. Ce n'est pas un serrage des flancs sur le
paquet de traverse : le tube de 60 fixe l'ecart des flancs, et les epaulements
de la traverse gardent 0,4 de jeu selon y.

## 4 bis. La traverse, et le poussoir

Ni l'une ni l'autre n'est plus un bloc.

**La traverse** est faite de **six plaques verticales de 8, jointives**, dont
le chant du bas forme la portee de 48 x 60 sur laquelle glisse le coin. Deux
tenons par plaque s'engagent dans une mortaise de 52 x 20,4 percee dans le
flanc a z 361,5 - 381,9, et prennent appui sur son arete SUPERIEURE. Chaque
plaque est une poutre de 64 de haut appuyee a 68,5 d'entraxe : 7,6 MPa de
flexion en majorant la charge concentree, coefficient 56. Le tenon mate a
26,5 MPa sur sa portee nette (38,4 x 5,9 par flanc, aretes cassees et
degagements deduits), et sa racine travaille a 11,5 MPa.

Le jeu de la mortaise en largeur, 4 mm, vaut exactement deux fois le rayon de
ses conges : l'arete portante droite fait donc tout juste les 48 mm du paquet
de tenons. Six toles empilees cumulent six fois la tolerance d'epaisseur
(EN 10029) : c'est pourquoi la mortaise est taillee sur la tole S355 MESUREE
des plaques (`EP_TOLE_REELLE_S355`), et non sur la cote nominale. En hauteur au contraire le jeu
reste a 0,4, parce que la hauteur du tenon est une cote de DECOUPE, pas
d'empilage.

Les pieds de tenon portent un **degagement** droit R1,5 et non un conge : un conge
deborderait de l'epaulement et viendrait mordre la face interieure du flanc --
le controle d'interference l'avait trouve. Les coins de la mortaise, eux, sont
de simples **conges** : un degagement en os de chien n'a de sens que si la
piece conjuguee doit porter DANS l'angle, et ici le paquet a 2 mm de jeu par
cote. Essaye sur le flanc de 10, il creusait une entaille au bout meme de la
ligne d'appui : 209 MPa au lieu de 130.

Il n'y a plus ni barreau 60 x 45, ni quatre taraudages, ni quatre vis, ni
quatre trous dans le flanc. Deux vis H M10 x 80 a filetage total, a 34
d'entraxe, tiennent le paquet ; elles ne reprennent aucune charge, mais a deux
elles gardent les plaques alignees. Le chant du bas est fraise (ou dresse au
papier abrasif sur un marbre) **les plaques serrees en paquet**, en une seule passe, alignees sur les faces hautes
des tenons ; le DXF porte 1 mm de surepaisseur sur ce chant.

Le paquet pese 1,54 kg. Ses plaques font 64 de haut parce que la mortaise est a
36 mm au dessus de la fente du coin, une valeur historique fixee quand
l'entretoise haute de la chape enjambait encore la fente ; la reduire
raccourcirait la traverse, mais deplacerait la mortaise et donc le calcul EF du
flanc. Le gain du tenon-mortaise est ailleurs : plus de barreau a acheter, plus
de taraudage, et une charge qui entre dans le flanc a 38 mm sous la membrure
haute.

**Le coulisseau** ne flechit pas : le coin appuie a la VERTICALE de la pile, sur
la meme empreinte, et la piece ne fait que transmettre 12 kN en compression,
soit 5,2 MPa. Son epaisseur de reference est donc passee de 36 a **30**, la
seule valeur que deux details imposent encore : 5 mm de matiere au dessus des
taraudages de guide du cote MINCE de la pente (12 + 4 + 5 = 21 minimum, il y en
a 23,8) et un chapeau au dessus de l'alesage du tourillon (20 + 2,7 + 6 = 28,7
minimum ; il fait 7,3). La piece pese 1,45 kg, et tout l'etage au dessus est
descendu de 6 mm.

**Le poussoir** n'etale que l'effort de la pile sur le patin de charge : aucune
surface fonctionnelle. C'est un empilage de **trois plateaux de 8, tous
perces** au diametre du tourillon ; c'est le patin de charge colle qui fait
fond. Debout, les plateaux glisseraient l'un sur l'autre : deux vis H M6 x 35,
tete en dessous et ecrou au dessus, les serrent en un bloc. Le bloc n'est pas
localise sur le patin : c'est le tourillon, colle dans le coulisseau, qui le
centre ; le patin, sans trou, est colle centre au trace.
0,97 kg, et plus d'alesage borgne a usiner.

**Les pieces de tole ont leurs aretes seulement ebavurees**, sans chanfrein
dessine ni modelise (09/10/2026 : les chanfreins du STEP genaient les
analyseurs de geometrie des sites de decoupe). Les calculs comptent pourtant
0,8 mm non portant a chaque bord, par prudence : les cinq joints du paquet de
traverse sous la plaque de bronze retirent 8 mm de portee sur ses 38, d'ou
7,6 MPa de contact au lieu d'environ 6.

## 5. Les lumieres

Reportees a x = +/- 44, de part et d'autre de la fente du coin, avec 15 mm de
matiere du cote de la fente et 14 mm du cote du bord du noeud. Le noeud porte
maintenant quatre ouvertures -- la fente du coin, les deux lumieres, et la
mortaise de traverse plus haut -- et les deux trous des vis de chape.

Les pattes prismatiques du coulisseau ont disparu. Le guidage se fait par les
**tetes de quatre CHC M8 x 12 ISO 4762**, tete lisse, vissees apres coup au
travers des lumieres dans quatre taraudages M8 des faces laterales. La tete,
diametre 13 et haute de 8, fait exactement l'epaisseur du flanc. La longueur
12 se compte sous la tete : toute la tige entre dans le taraudage de 16.

Un cylindre sur un plan ne porte que sur une LIGNE. Il ne peut donc pas se
coincer en biais comme le faisait la patte prismatique, dont les deux faces
devaient rester paralleles aux joues de la lumiere, et il est insensible aux
rotations autour de son axe comme autour de la ligne de contact. C'est le vrai
remede a l'hyperstatisme des quatre guidages, bien plus que la reduction de
section qui l'avait precede.

Le montage y gagne autant : on ferme le cadre sur le coulisseau, PUIS on visse
les quatre guides au travers des lumieres. Plus besoin d'engager des tenons a
l'aveugle en presentant le second flanc.

La butee de course y gagne aussi : la tete, diametre 13, talonne dans un bout
de lumiere de rayon 7. Deux cercles de rayons voisins, c'est un contact
CONFORME de rayon equivalent 91 mm, la ou le chant d'une patte sur un
demi-cercle etait un contact quasi ponctuel.

Et les lumieres se reduisent beaucoup : **14 x 28,8**, contre 17 x 31,8 avec
les guides M10 de la version precedente et 20,6 x 63,4 avec les pattes.

Le calcul elements finis donne **213 MPa au maximum**, coefficient 2,02 a froid
et 1,83 a 150 C, dans la membrure basse sous le montant cote appui, et 0,335 mm
de fleche. Le meme point vaut 187 MPa a l'autre appui : sur une piece
symetrique, c'est le bruit de maillage. Viennent ensuite 187 MPa a l'angle de
la mortaise ou portent les tenons, 130 et 125 MPa aux consoles d'appui,
103 MPa dans les ligaments entre fente du coin et lumiere, et 90 MPa aux angles
bas du noeud. Le 99,9e centile est a 87 MPa.

Si le maximum devait etre repris, le levier n'est ni le conge R22 du
raccordement membrure basse / montant (balayage R10 a R26 : bruit de maillage)
ni les ouvertures du noeud, mais l'epaisseur ou la nuance de la tole : repli
10 mm en S355 ou S460.

## 6. Le reste de ce que la position debout impose

- **Butee d'about : supprimee le 22/09/2026**, avec ses oreilles et ses deux
  tiges transversales.
- **Calage de la poutrelle debout : POINT OUVERT, ASSUME.** Debout, rien ne
  retient la poutrelle selon x, devenu vertical, que le frottement aux appuis,
  environ 0,15 F acier sur acier : il ne depasse son poids (218 N sur l'about
  bas) qu'au dela de 1,5 kN environ. En dessous -- mise en place, precharge de
  0,5 kN, dechargement, et apres rupture -- le poids passe par la chaine de
  mesure : patin de charge, poussoir visse, tourillon (jeu de 0,4),
  coulisseau, tetes de guide (jeu de 0,5), et pousse la tete de charge de
  cote. Les patins rainures ne tiennent que y. Deux pistes, non retenues a ce
  jour : une cale amovible de 14 entre l'about bas de la poutrelle (x -420) et
  le bord de fenetre des deux montants (x -435), retiree une fois la charge
  au dessus de 1,5 kN ; ou la consigne de ne dresser le cadre que charge au
  dela de ce seuil.
- **Socle : les memes pieds a mi-bois que couche, aux coins, inclines.**
  Chaque coin du flanc porte une encoche inclinee de 38 degres sur le grand
  cote (le conge R20 a disparu, l'encoche le remplace), profonde de 28 depuis
  le coin vif ; les deux pieds de l'about font un V, larges de 518,4 (fentes a 500 d'entraxe, 5 de bord), et posent
  par leur arete basse, 9,5 mm sous l'about, sur les appuis des crochets qui
  les calent par leurs dents : c'est la, et non a la largeur de la base (447
  entre aretes), que le cadre tient debout. Pourquoi 38 et non 45 : a 45, avec
  les trous de coin alors a z 40, le pied passait a 1 mm du tube d'entretoise
  du coin ; aujourd'hui, a 38 degres et trous a z 50, il en passe a 11,6 mm,
  11 de la rondelle de l'ecrou. L'encoche du coin bas entame le bout de la
  membrure basse : l'appui est a 213 MPa a l'EF, 2,02 a froid et 1,83 a 150 C
  en 42CrMo4. Au modele, au DXF et au plan 01.
- **Les pieds en V se montent UN PAR UN**, le cadre couche sur ses pieds :
  chacun s'emboite en coulissant le long de SA propre encoche, a +38 degres
  pour le coin bas de l'about, a -38 pour le coin haut. Ces deux directions
  font 76 degres entre elles et aucune n'est la verticale : on ne descend pas
  le cadre dans deux pieds deja poses. Les nodes serrent de 0,1 par cote :
  maillet. L'ordre complet est dans `NOMENCLATURE.md`.
- **Le fond de l'etuve ne porte pas le cadre.** Quatre crochets de la meme
  tole (05c), dans le plan des flancs, pendent aux parois qui font face aux
  aretes des deux pieds en V ; chaque pied pose par son arete basse sur deux
  appuis, a 245,8 de part et d'autre de l'axe, et la dent de chaque appui entre
  dans la fente du pied. Parois de 1 mm percees de trous carres de 10 au pas de
  40 et 30 en alternance : chaque crochet pend par quatre langues de 6 a bec, la plus basse a 10 du bas du crochet,
  de 3 (tete de 9, qui passe le trou de face avant de descendre), et porte en bas un appui de 60 avec une dent
  qui entre dans une fente du pied a 5 du bout : le cadre est cale. La largeur
  interieure entre ces parois, 538, confirmee le 05/10/2026, place la dent sur l'appui a 47,2
  de la paroi ; le pied et le crochet sont bons a decouper.
- **Entree dans l'etuve.** On accroche d'abord les quatre crochets. La porte
  est du cote de la tige : les pieds de 518,4 entrent selon y, et leur bout
  arriere doit passer au dessus des dents de 4,5 mm des deux crochets cote
  porte. On entre donc le cadre pieds tenus 5 mm au dessus des appuis jusqu'au
  fond, puis on le descend sur les quatre dents.
- **Les deux pieds de la position couchee se retirent** : autour du cadre
  debout, la place est prise par les pieds en V et les crochets. On souleve le
  cadre, ils restent sur la paillasse.
- **Rien ne peut tomber** quand la tete devient horizontale : le tourillon est
  colle dans le coulisseau et entre de 7,9 mm dans le poussoir au repos (4,9
  avec toutes les cales), davantage sous charge ; le poussoir est enfile dessus, et ses plateaux sont visses en un bloc.

## 7. Orientation a respecter dans l'etuve

La tige de commande sort dans la direction de l'epaisseur du cadre. Il faut
placer le banc de facon que cette direction pointe vers la PORTE. Les 440 mm du
cadre se mettent alors en travers, avec 50 mm de jeu de chaque cote, ou se
logent les pieds en V et les crochets.

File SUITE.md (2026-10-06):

# Ce qui a ete corrige, ce qui reste a gagner, ce qu'il faut savoir

> **HISTORIQUE -- etat au 11/09/2026** : flanc en tole de 10 S355, vis de
> charge verticale M20, banc couche seulement. La conception a beaucoup change
> depuis : tole de 8 en 42CrMo4, commande par coin normale aux flancs, position
> debout dans l'etuve, traverse a tenons, guidage par tetes de vis. Ce document
> n'est garde que pour la trace des decisions ; les chiffres ci-dessous sont
> ceux du 11/09. Pour l'etat courant, voir `SPEC.md`, `NOMENCLATURE.md` et
> `DEBOUT.md`. Les remarques entre crochets et la section 5, ajoutees le
> 02/10/2026, disent ce que chaque point est devenu.

Huit revues independantes ont produit 89 propositions et 70 signalements
d'incoherence (fichier brut supprime le 06/10/2026, reste dans l'historique git). Voici le tri.

## 1. Corrige dans le modele

| point | avant | apres |
|---|---|---|
| Rondelles Belleville | A50 donnee a 12,9 kN et 0,77 kN/mm, loi lineaire | DIN 2093 reelle : l0 4,3, h0 1,3, 18,5 kN a plat, loi d'Almen-Laszlo, 1243 N/mm en secant a 12 kN |
| Ecrasement a 12 kN | 15,6 mm annonces | 9,65 mm calcules |
| Graduation de charge | un pas constant | non lineaire, tabulee et gravee |
| Axe neutre de la poutrelle | 53,5 mm, beton nu | 50,86 mm, section homogeneisee avec les deux plats |
| Point de contact d'appui | face inferieure du patin | fond de la rainure, 1,5 mm plus haut |
| Justification du rayon R65 | roulement sans glissement | faux : c'est un balancier. Rayon porte a R150, choisi pour la pression de contact |
| Pression de Hertz | 412 MPa, conclusion elastique a 20 degres | 271 MPa, coefficient 1,77 sur l'ecoulement au contact a 150 degres [02/10 : flanc de 8 portant sur 6,4 mm, 339 MPa ; limite 480, celle du patin S355 a chaud ; coefficient 1,42] |
| Aplatissement de la pile | rien ne l'empechait | le bas de la lumiere est une butee : effort plafonne a 14,4 kN |
| Rainure du patin | 10,5 mm, 0,25 de jeu, moins que la planeite d'une tole | 11,5 mm, 0,75 de jeu [sur la tole de 10 ; depuis le 02/10, 9,5 sur la tole de 8 : tole reelle + 2 x 0,75] |
| Patin d'appui | 80 mm, plus court que le bossage elargi | 90 mm |
| Manoeuvre de la vis | tete six pans creux, douille difficile a engager | tete percee 8 mm pour barre traversante [sans objet : la vis verticale a disparu avec la commande par coin, tige M16 manoeuvree a la douille] |
| Temoin thermique | plat de 3 mm decoupe dans une tole de 10 | tole de 10 [supprime depuis] |
| Orientation debout | presentee comme possible | impossible, le cadre fait 960 de long dans une etuve de 500 [rendue possible depuis par la commande par coin : voir DEBOUT.md ; etuve supposee 540, a confirmer] |
| Butee d'about | dans la nomenclature | supprimee, elle ne servait qu'a l'orientation debout [reprise pour la position debout, puis de nouveau supprimee le 22/09] |
| Col de mesure | 8 x 10, entaille dans la membrure | supprime : la membrure pleine donne 16 microdeformations par kN, soit 62 N de resolution |
| Specification | fichier a la main, perime des la premiere modification | engendre par `spec.py` depuis `params.py` |

## 2. Tranche par le calcul

Le flanc a ete calcule aux elements finis sous CalculiX, 146 000 noeuds,
elements du second ordre, appuis glissants, 6 kN au noeud.

- **von Mises maxi 134 MPa, coefficient 2,65 sur S355, fleche 0,197 mm.**
  Le point chaud est au raccordement membrure basse / montant, cote appui.
  [02/10 : flanc de 8 en 42CrMo4, 213 MPa, 2,02 a froid et 1,83 a 150 C,
  0,335 mm de fleche ; le point chaud est dans la membrure basse sous le
  montant.]
- **Le conge de ce raccordement est un optimum a R22.** Porte a R25, la
  contrainte monte a 152 MPa : le conge mange la matiere du chemin d'effort au
  lieu d'adoucir une entaille. C'est le seul endroit du cadre ou agrandir un
  conge est nuisible. [CONTREDIT depuis : rejoue le 16/09 avec un blocage
  propre, le balayage R10 a R26 donne 151 a 160 MPa sans tendance, du bruit de
  maillage. Le rayon n'est pas le levier.]
- **Les sept trous d'allegement de la membrure basse coutent 6 MPa** sur le pic
  (134 contre 127 sans) et economisent 0,2 kg par flanc. Ils ne sont pas a
  l'origine du point chaud. Deux revues se contredisaient sur ce point : l'une
  voulait amincir la membrure basse a 18 mm, l'autre interdisait d'y percer.
  Les deux avaient tort. La membrure basse porte un moment CONSTANT de 180 N.m
  entre les appuis : on ne peut pas l'amincir a 18, mais on peut l'ajourer.
- **Une proposition ne survit pas a la geometrie reelle** : mettre les montants
  au droit des appuis pour supprimer la console de 55 mm. Impossible, les
  appuis sont a +/- 375 et les abouts de la poutrelle a +/- 420 : les montants
  passeraient dans la poutrelle.

## 3. A gagner, non applique

Chaque ligne est chiffree et independante. Rien n'est bloquant.

| gain | ce qu'il faut faire | ce qu'il coute |
|---|---|---|
| **-5,3 kg** (15 % du cadre) | flanc en tole de 8 au lieu de 10 | Hertz passe de 271 a 303 MPa (coefficient 1,58 au lieu de 1,77), pic de von Mises a 167 MPa (coefficient 2,1), rainure du patin ramenee a 9,5. Les deux entretoises de mi-bielle sont deja au plan, le flambement reste couvert. |
| **-1 taraudage M20** | poche hexagonale decoupee dans la traverse + ecrou M20 standard | la poche dans 45 mm est a la limite du laser, le jet d'eau la fait. Le filet devient un consommable remplacable. |
| **4 patins d'appui -> 2, 4 fraisages -> 0** | un patin unique 100 x 100 x 10 pontant les deux flancs par ligne d'appui, la rainure etant menagee par deux cales rapportees | +2 cales plates. Pression sur beton 1,5 MPa au lieu de 1,7. Tolerance de pose en y bien plus confortable. |
| **couple de manoeuvre divise par 2** | pointe de vis spherique R50 trempee, portant sur une rondelle trempee lamee dans le coulisseau | 1 tournage + trempe, 1 lamage, 1 rondelle du commerce. Sans la rondelle trempee la pointe indente le S355 des le premier chargement. |
| **6 kN en appui matiere au lieu du frottement de deux boulons** | traverse en tenon-mortaise : tenon 40 x 10 sur chaque about, mortaise correspondante dans le noeud | mortaise cotee au plus juste en hauteur. Les boulons deviennent de simples retenues. |
| **-1 piece** | supprimer le contre-ecrou M20 | le filetage M20 pas 2,5 est autobloquant avec une marge de 4 sur l'angle de frottement. A vide et sous la ventilation, la vis peut bouger seule. |
| **-0,5 kg, retenue a la rupture** | prolonger la lumiere vers le bas et dimensionner son fond pour encaisser les 52 J stockes dans la pile si la poutrelle disparait d'un coup | ecrasement local d'environ 1 mm en fond de lumiere apres un evenement pleine energie, a controler. |

Le passage du flanc a 8 mm est le seul gain de masse important. Pour un banc
manipule a deux, 36,6 kg n'est pas genant, et les coefficients actuels (2,65 en
von Mises, 1,77 au contact) sont confortables. Je le laisse en option plutot
qu'en decision. [Il a ete applique le 17/09, en 42CrMo4 : voir la section 5.]

## 4. A savoir pour la conduite d'essai

- **Le frottement d'appui coute quelques pour cent sur le moment.** Le bossage
  est un balancier : il n'absorbe pas le recul de 0,06 mm de la fibre basse a
  la fissuration. Pour le supprimer il faudrait un vrai galet libre sur une des
  deux lignes d'appui.
- **La lecture de charge par le coulisseau est un indicateur**, pas une mesure.
  Elle englobe la souplesse du cadre (0,20 mm a 12 kN ; 0,335 mm avec le flanc
  de 8) et la fleche de la poutrelle. La reference est la fibre sur la membrure haute.
- **Le revetement de la fibre est a verifier.** L'acrylate standard ne tient pas
  150 degres C. Il faut du polyimide, ou de l'or pour les temperatures hautes.
- **Palier de stabilisation d'au moins 2 heures** avant toute lecture : avec
  107 mm d'epaisseur, la constante de temps de la poutrelle est d'environ
  90 minutes.
- **Reprendre la charge a chaque palier** : les rondelles relaxent de quelques
  pour cent au dela de 100 degres C.
- **Coller les patins en place**, cadre monte, sous 0,5 kN de precharge. C'est
  l'epoxy qui rattrape l'hyperstaticite des quatre contacts. Post-cuire selon
  la notice Duralco avant toute mise en charge.
- **Effort a la fissuration estime a 5,1 kN** pour un beton a 4 MPa, section
  homogeneisee. La butee de course intervient a 14,4 kN, le cadre est calcule
  pour 12 kN : trois marges bien separees.
- **La profondeur de l'enceinte n'est pas connue.** C'est elle qui fixe le
  recul possible de la camera et donc la faisabilite optique de la correlation
  d'images. A verifier avant de commander la tole. [02/10 : etuve supposee
  540 x 540 x 1400, toujours A CONFIRMER ; le pied et le crochet en
  dependent. 05/10 : largeur 538 confirmee.]
- **Planeite de la tole a la livraison** : l'EN 10029 autorise 9 mm de fleche
  sur 1000 mm en classe N. Demander la classe A, ou faire dresser les flancs
  avant percage des appuis.
- **Precision utile** : l'entraxe des bossages a +/- 0,3 mm et leur coplanarite
  a 0,3 mm suffisent, puisque les patins sont colles en place. Ne pas
  sur-specifier.

## 5. Suite donnee (etat au 02/10/2026)

| point du paragraphe 3 | suite |
|---|---|
| flanc en tole de 8 | APPLIQUE le 17/09, en 42CrMo4 recuit +A, Re >= 430 exige au certificat 3.1 : 213 MPa a l'EF, 2,02 a froid, 1,83 a 150 C, cadre de 35,2 kg. Rainure du patin ramenee a 9,5 le 02/10. |
| -1 taraudage M20, -1 contre-ecrou M20, pointe de vis spherique | SANS OBJET : la vis verticale M20 a disparu avec la commande par coin (tige M16 normale aux flancs, coin d'acier garni de deux plaques de bronze du commerce). |
| 4 patins d'appui -> 2 | NON applique : quatre patins rainures 90 x 20 x 10, colles en place, un jeu par eprouvette. |
| traverse en tenon-mortaise | APPLIQUE : six plaques de 8 a tenons, portees par l'arete haute d'une mortaise des flancs ; plus aucune vis de traverse. |
| retenue a la rupture | NON applique en tant que tel : le bas de la lumiere est la butee de course (contact conforme entre la tete de guide et le bout de lumiere) ; l'energie de rupture n'y a pas ete rechiffree. |

Ce qui est venu depuis, hors de cette revue : position debout dans l'etuve
(pieds en V et crochets), guidage du coulisseau par les tetes de quatre CHC M8,
poussoir en plateaux visses, butee de vis en platines de tole, entretoise de
sommet (flambement 39 au lieu de 13,7), visserie M10 a ecrous autofreines tout
metal. Le detail est dans `SPEC.md` et `DEBOUT.md`.

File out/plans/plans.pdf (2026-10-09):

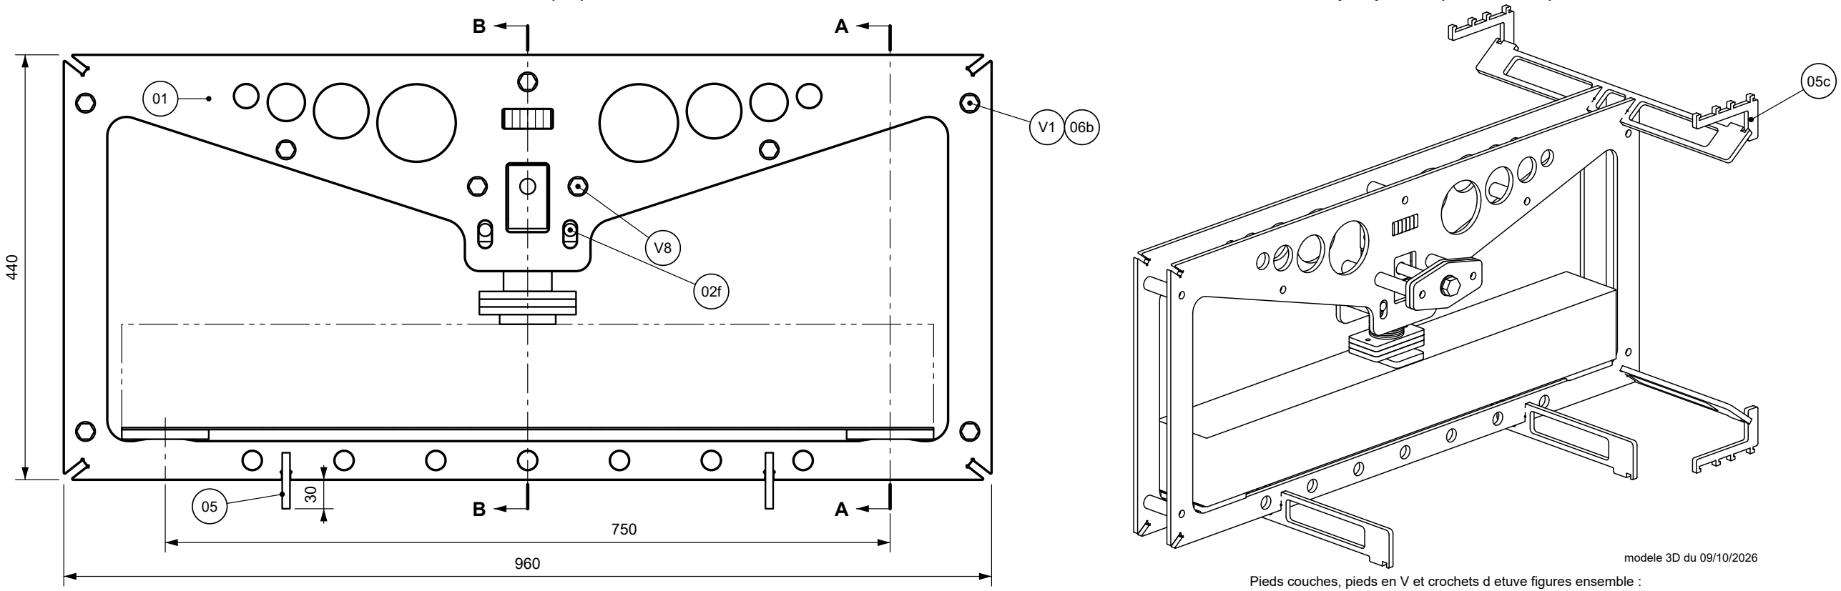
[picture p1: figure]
modele 3D du 09/10/2026

# BANC DE FLEXION - ENSEMBLE

indice B
05/10/2026

## rep. 00

matiere
voir nomenclature

brut

quantite
1

echelle
1:5 sauf indication

cotes en mm
tol. generale ISO 2768-m

banc de flexion
poutrelle 103x107x840

Masse du cadre 34,5 kg. Reperes : NOMENCLATURE.md (Vn : visserie).

Debout dans l etuve : 969,5 de haut, 458,6 x 518,4 en plan ; etuve 538 x 528,4 x 1400.

Hors tout couche sur pieds : 960 x 518,4 x 470 (x, y, z) ; flancs 76.

0,425 mm de coulisseau et environ 549 N par tour de vis.

Reglage par coin acier a 12 deg et vis M16 normale aux flancs :

Lecture de charge : 9,65 mm de coulisseau a 12 kN.

Pile Belleville, 12 rondelles EN 16983 A50 : 18,5 kN a plat, course 15,6 mm.

Eprouvette : poutrelle 103 x 107 x 840, en trait mixte a deux tirets.

Flexion 3 points, portee 750, capacite 12 kN.

### elevation (1:5)

### coupe A-A (1:2)

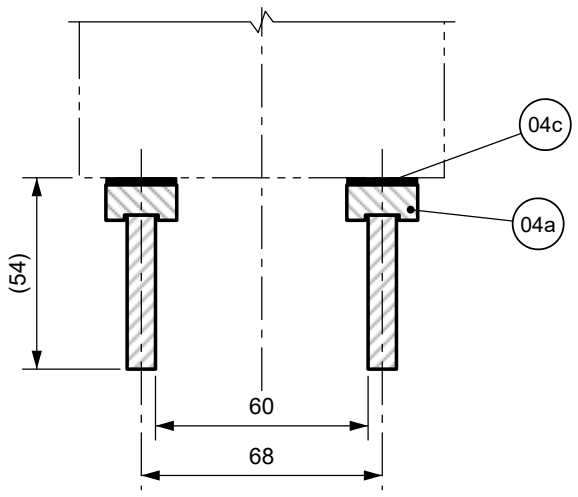
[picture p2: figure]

Les flancs portent SOUS les plats colles : la face laterale de la poutre reste degagee. Pieds 05, au-dela du plan, non figures.

### coupe B-B (1:2,5)

85,5 | 137,5
| 160

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
02d 07b | 07 | V6

02a

06a

V7 V5

V8

Le coin AVANCE VERS LA CHAPE en chargeant ; repousse vers son bout epais, il TIRE la vis vers l interieur :
la tete appuie, par deux rondelles trempees, sur la face exterieure des 2 platines ; monte a l envers, la vis ne retiendrait rien. Douille sur la tete : 116,7 mm devant la tete de vis dans l etuve de 528,4, 10 de marge pour le decentrage du cadre.
En trait mixte a deux tirets, le coin 02c en fin de course : 56,5 depuis le repos.

NIVEAUX (z depuis le chant bas des flancs)
rep. | piece | z bas | z haut
03 | traverse, 6 plaques | 325,7 | 389,7
06c | plaque de frottement haute | 319,7 | 325,7
02c | coin au repos, a y = 0 | 282,7 | 319,7
06d | plaque de frottement basse, y = 0 | 276,6 | 282,7
02a | coulisseau, a y = 0 | 246,6 | 276,6
06a | tourillon | 187,1 | 266,6
02e | pile Belleville libre (+ cales V4) | 195 | 246,6
02b | poussoir, 3 plateaux visses (V3) | 171 | 195
04b | patin de charge | 161 | 171
- | poutrelle (eprouvette) | 54 | 161
04c | plats colles | 52 | 54
04a | patins d appui, x = +/- 375 | 42 | 52
02d | vis M16 : axe | 303,7

### perspective (sans echelle)

Pieds couches, pieds en V et crochets d etuve figures ensemble : debout, les pieds couches restent sur la paillasse.

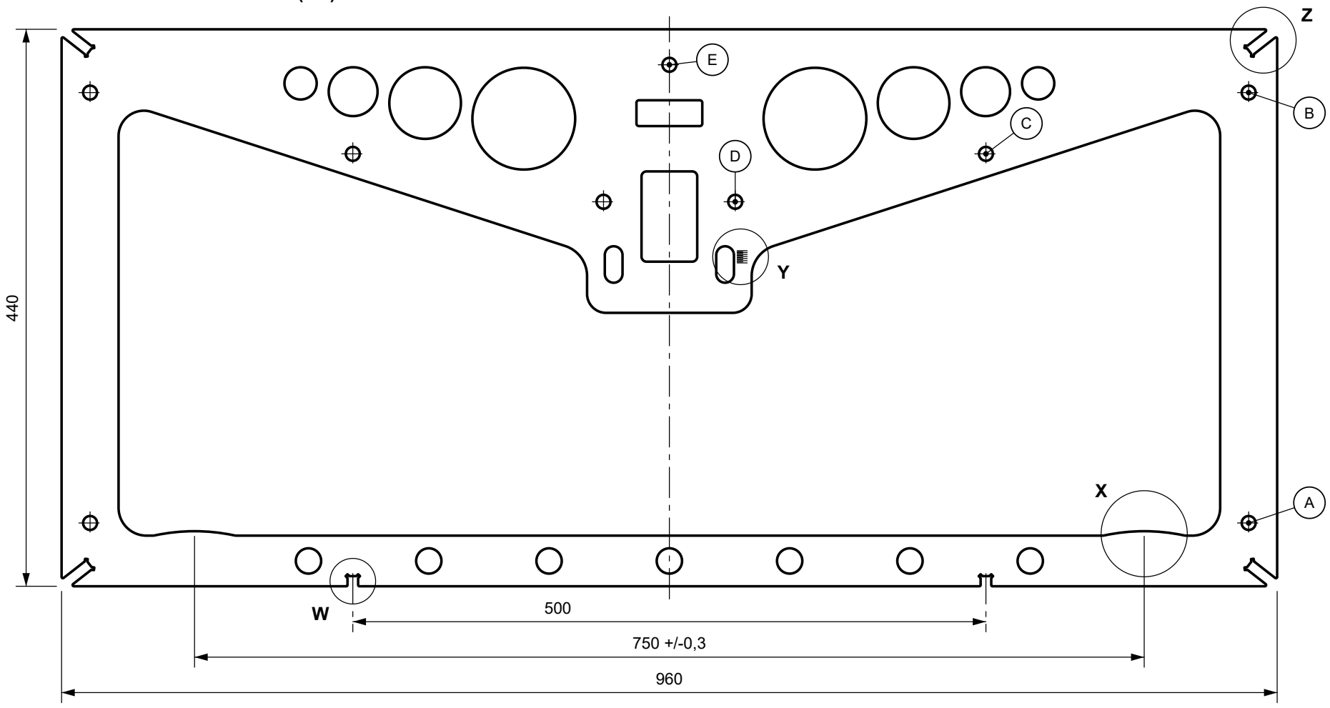
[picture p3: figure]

# FLANC EN TREILLIS

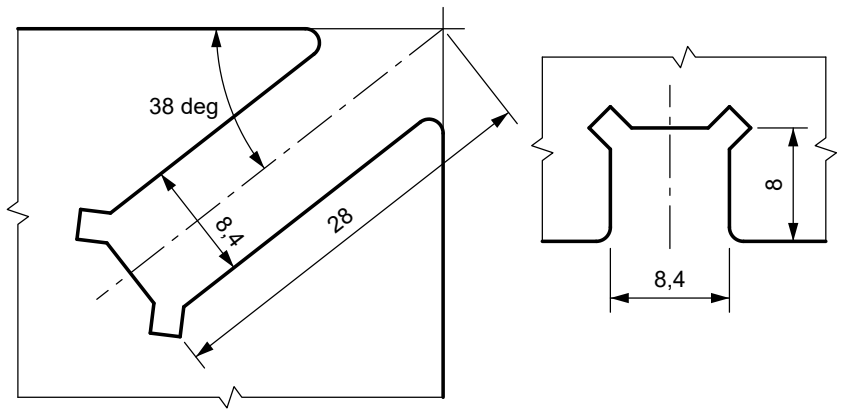
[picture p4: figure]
38 deg

indice B
05/10/2026

## rep. 01

matiere
42CrMo4 +A

brut
tole 8 mm, cert. 3.1, Re >= 430

quantite
2

1:4 - details 1,5:1 et 2:1

Sabler les 2 faces a l'identique (planeite) ; huile ester HT en film essuye, ni minerale ni silicone. Masse : 10,2 kg.

Planeite 0,5 sur 960, ne pas redresser a chaud ; sommets des bossages coplanaires a 0,3.

le second, tourne de 180 deg autour de Z, a sa graduation le long de la lumiere -X.

Contour symetrique en X, graduation d'un seul cote : deux flancs identiques, face gravee a l'exterieur ;

Aretes ebavurees, sans chanfrein, bossages compris (non repris), puis sablage corindon et brunissage noir mat.

Mesurer les deux toles livrees, regler EP_TOLE_REELLE_42 (42CrMo4) et EP_TOLE_REELLE_S355 (S355JR) et regenerer les DXF avant decoupe.

mortaise 52 = 6 x tole + jeu 4.

Encoches et mortaise taillees sur la tole S355 REELLE des pieds et de la traverse (EP_TOLE_REELLE_S355 = 8) : encoches 8,4 = tole + jeu 0,4 ;

Matiere : 42CrMo4 recuit +A, tole 8 mm : certificat 3.1 EN 10204 avec essai de traction, Re >= 430 MPa a 20 C.

Decoupe et gravure laser d'apres flanc.dxf : calque DECOUPE coupe, GRAVURE marque sans traverser (detail Y).

### VUE DE LA FACE GRAVEE (1:4)

### DETAIL X (1,5:1)

bossage d'appui, 2 ex.
R150

R10

3,5

(66,6)

Bombe R150 choisi pour le contact, 3 kN par bossage : Hertz 339 MPa sur 6,4 portants (8 - 2 x 0,8 de bord non compte), limite 480 MPa (patin S355 a 150 C), coefficient 1,42.

### DETAIL Y (2:1) graduation

9,5 | 8

0 kN

6 kN

12 kN

Traits graves, sans chiffres, de 4,5 aux kN impairs.
Zero : tangente haute de la tete de guide (trait mixte),
pile libre, Z 265,10.
Z de chaque trait : tableau GRADUATION. Profondeur 0,2 mini, traits repasses en blanc HT.

### DETAIL Z (2:1)

encoche de coin, 4 ex. symetriques

### DETAIL W (2:1)

encoche du chant bas, 2 ex.

Details Z et W : angles du fond degages par une poche carree de 2,1 tournee a 45 deg, centree sur l'angle vif (3 traits) ; bouches R1.

PERCAGES (X depuis l'axe, Z depuis le chant bas)
rep | nb | X | Z | diam | fonction
A | 2 | +/-457,5 | 50 | 11 | entretoise basse
B | 2 | +/-457,5 | 390 | 11 | entretoise haute
C | 2 | +/-250 | 341,6 | 11 | entretoise de bielle
D | 2 | +/-52 | 303,7 | 11 | entretoise et tirant de chape
E | 1 | 0 | 412 | 11 | entretoise de sommet

AJOURS (meme origine)
nb | X | Z | diam
2 | +/-115 | 369,4 | 81,2
2 | +/-192,9 | 381,7 | 56,6
2 | +/-249,8 | 390,7 | 38,6
2 | +/-291,3 | 397,3 | 25,5
1 | 0 | 20 | 20
2 | +/-95 | 20 | 20
2 | +/-190 | 20 | 20
2 | +/-285 | 20 | 20

FENETRE (sommets en coins vifs fictifs)
sommet | nb | X | Z | conge
angle bas | 2 | +/-435 | 40 | R22
tete de montant | 2 | +/-435 | 383,2 | R20
aisselle de noeud | 2 | +/-65 | 263,2 | R25
angle bas du noeud | 2 | +/-65 | 216 | R15
Sommets relies par des droites ; arete de bielle a 17,97 deg ; bossages d'appui : cote 750 et detail X.

DECOUPES INTERIEURES (X de l'axe de la decoupe)
decoupe | nb | X | Z bas a haut | largeur | angles
fente du coin | 1 | 0 | 256,4 a 327,7 | 44 | R4
lumiere oblongue | 2 | +/-44 | 239,8 a 268,6 | 14 | R7
mortaise de traverse | 1 | 0 | 363,5 a 383,9 | 52 | R2

GRADUATION (detail Y)
kN | Z | kN | Z
0 | 265,10 | 7 | 259,74
1 | 264,38 | 8 | 258,91
2 | 263,65 | 9 | 258,07
3 | 262,90 | 10 | 257,21
4 | 262,13 | 11 | 256,33
5 | 261,35 | 12 | 255,45
6 | 260,55

### 02a COULISSEAU A TETE INCLINEE (1:1)

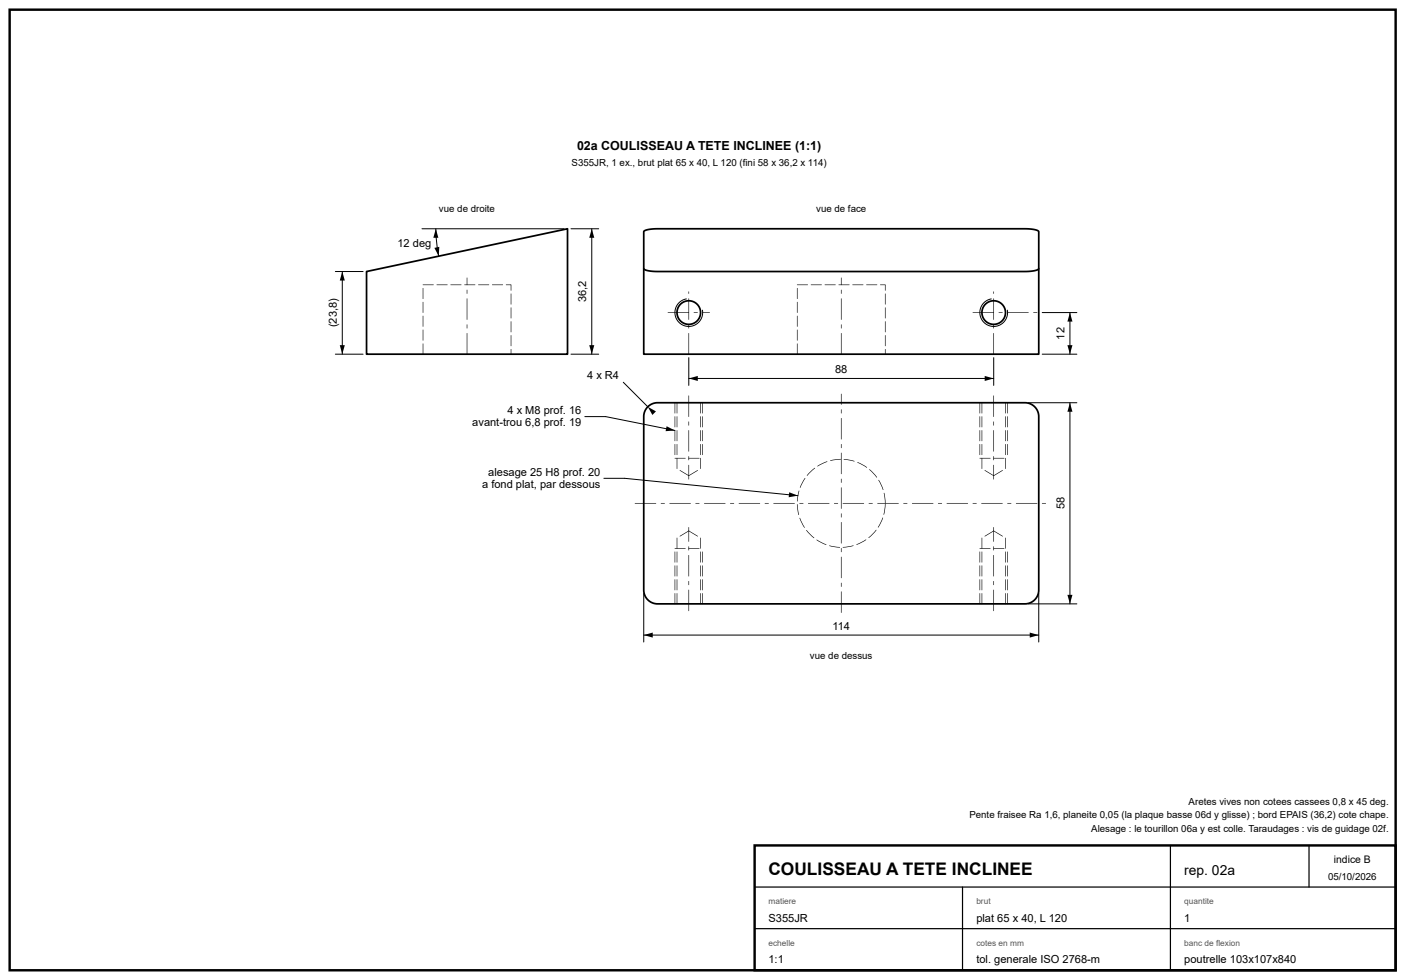
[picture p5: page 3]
indice B; rep. 02a; matiere S355JR; brut plat 65 x 40, L 120; quantite 1; 12 deg

S355JR, 1 ex., brut plat 65 x 40, L 120 (fini 58 x 36,2 x 114)

vue de droite

vue de face

4 x M8 prof. 16
avant-trou 6,8 prof. 19

alesage 25 H8 prof. 20
a fond plat, par dessous

vue de dessus

Aretes vives non cotees cassees 0,8 x 45 deg.

Pente fraisee Ra 1,6, planeite 0,05 (la plaque basse 06d y glisse) ; bord EPAIS (36,2) cote chape.

Alesage : le tourillon 06a y est colle. Taraudages : vis de guidage 02f.

COULISSEAU A TETE INCLINEE

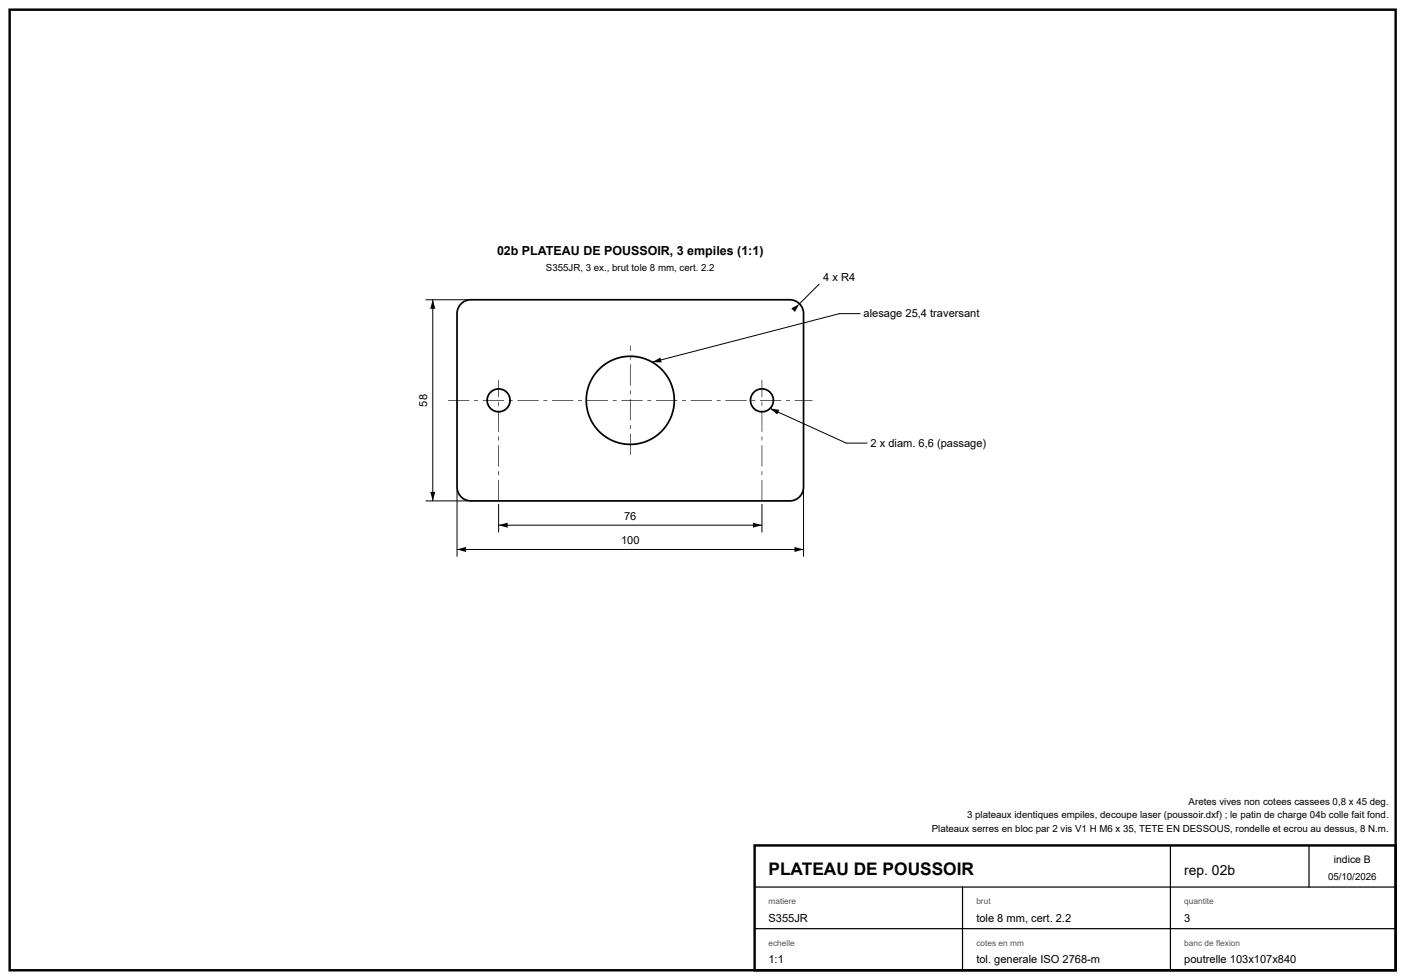
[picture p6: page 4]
indice B; rep. 02b; matiere S355JR; quantite 3; alesage 25,4 traversant; 2 x diam. 6,6 (passage)

02b PLATEAU DE POUSSOIR, 3 empiles (1:1)

S355JR, 3 ex., brut tole 8 mm, cert. 2.2

Aretes vives non cotees cassees 0,8 x 45 deg.

3 plateaux identiques empiles, decoupe laser (poussoir.dxf) ; le patin de charge 04b colle fait fond.

Plateaux serres en bloc par 2 vis V1 H M6 x 35, TETE EN DESSOUS, rondelle et ecrou au dessus, 8 N.m.

PLATEAU DE POUSSOIR

brut
tole 8 mm, cert. 2.2

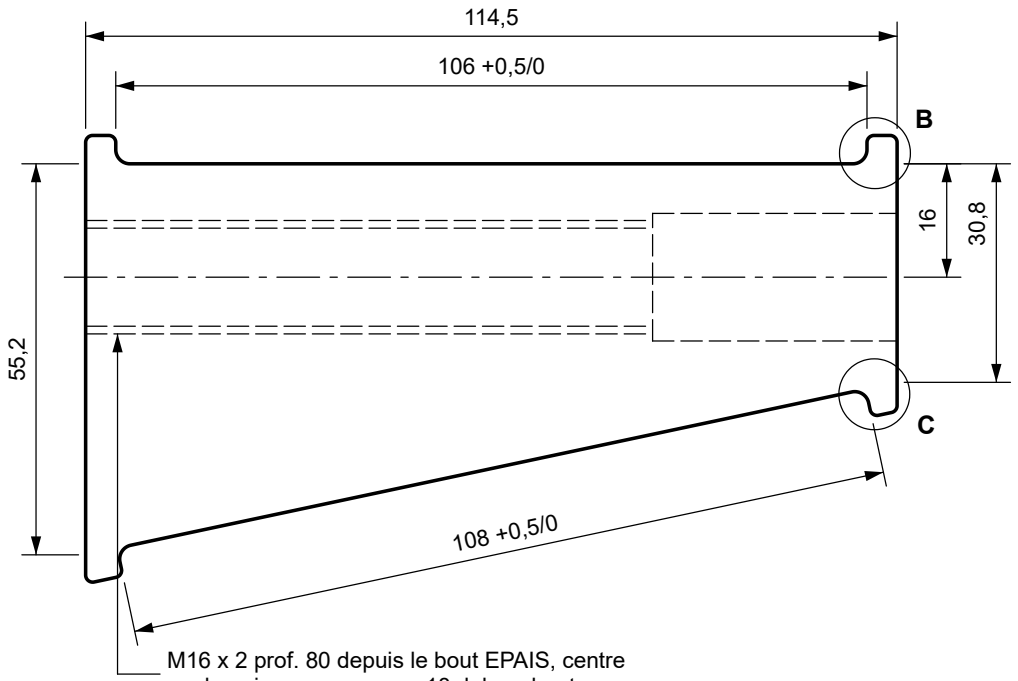
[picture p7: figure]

# COIN DE COMMANDE

indice B
05/10/2026

## rep. 02c

matiere
C45

brut
plat 70 x 45, L 120

quantite
1

1:1 - details 4:1

SENS DE MONTAGE : bout EPAIS du coin du cote oppose a la chape.

02c : flancs du filet a 9,2 MPa ; pate cuivre (haute temperature) dans le taraudage.

(helice 2,48 deg, frottement 5,28 deg a mu 0,08 : marge x2,13 ; un Tr16x4 tomberait a x0,91, reversible).

02c : autobloquant seulement si mu > 0,106 : on n y compte pas, c est le filet M16 x 2 qui tient la charge

02c : commande 5,5 kN, couple 14,5 N.m a 12 kN ; un tour de vis : 0,425 mm de coulisseau, environ 549 N.

02c : plaques de bronze usinees 06c (38 x 102) et 06d (38 x 104), ep. 6, tenues par les rebords, points de silicone HT.

02c : pente du dessous (12 deg, celle du coulisseau) ; faces interieures des rebords du dessous NORMALES a la pente ; angles R1.

02c : logements centres sur la longueur, sieges plans a 0,05 ; 55,2, 30,8 et 16 depuis les plans des sieges prolonges.

Aretes vives non cotees cassees 0,8 x 45 deg.

### 02c COIN DE COMMANDE, epaisseur 40 (1:1)

C45, 1 ex., brut plat 70 x 45, L 120 (fini 63 x 40 x 114,5)

M16 x 2 prof. 80 depuis le bout EPAIS, centre sur l epaisseur ; passage 18 debouchant

### DETAIL B (4:1)

rebords du dessus, 2 ex.
largeur (4,25) ; pied : conge R2 (fraise de 4)

4

R2 | R1

### DETAIL C (4:1)

rebords du dessous, 2 ex.
largeur (4,43) en projection ; pied R2 comme B

4

# TRAVERSE - PLAQUE A TENONS

indice B
05/10/2026

## rep. 03

matiere
S355JR

brut
tole 8 mm, cert. 2.2

quantite
6 plaques identiques

2:1 - detail 10:1

Les tenons portent par leur face HAUTE sur l arete superieure de la mortaise du flanc : pas de vis de traverse.

Angles du contour non cotes : R2 ; pieds de tenon : detail A.

Aretes ebavurees APRES le fraisage, sans chanfrein,puis paquet resserre sur V2, chants fraises poses sur un marbre.

Chant fraise : planeite 0,05 sur le paquet, Ra 1,6 ; c est le plan de glissement de la plaque de bronze 06c, sans rectification.

12 tenons (2 cales de plus de 6 sous les tenons, la coiffe passe entre), fraise a 58 de ces faces.

CHANT DU BAS FRAISE EN PAQUET : les 6 plaques serrees par les 2 vis V2, paquet retourne et pose sur les faces HAUTES des

Decoupe laser d apres traverse.dxf (calque DECOUPE) : le DXF est le BRUT, chant du bas descendu de 1 (65 de haut au lieu de 64).

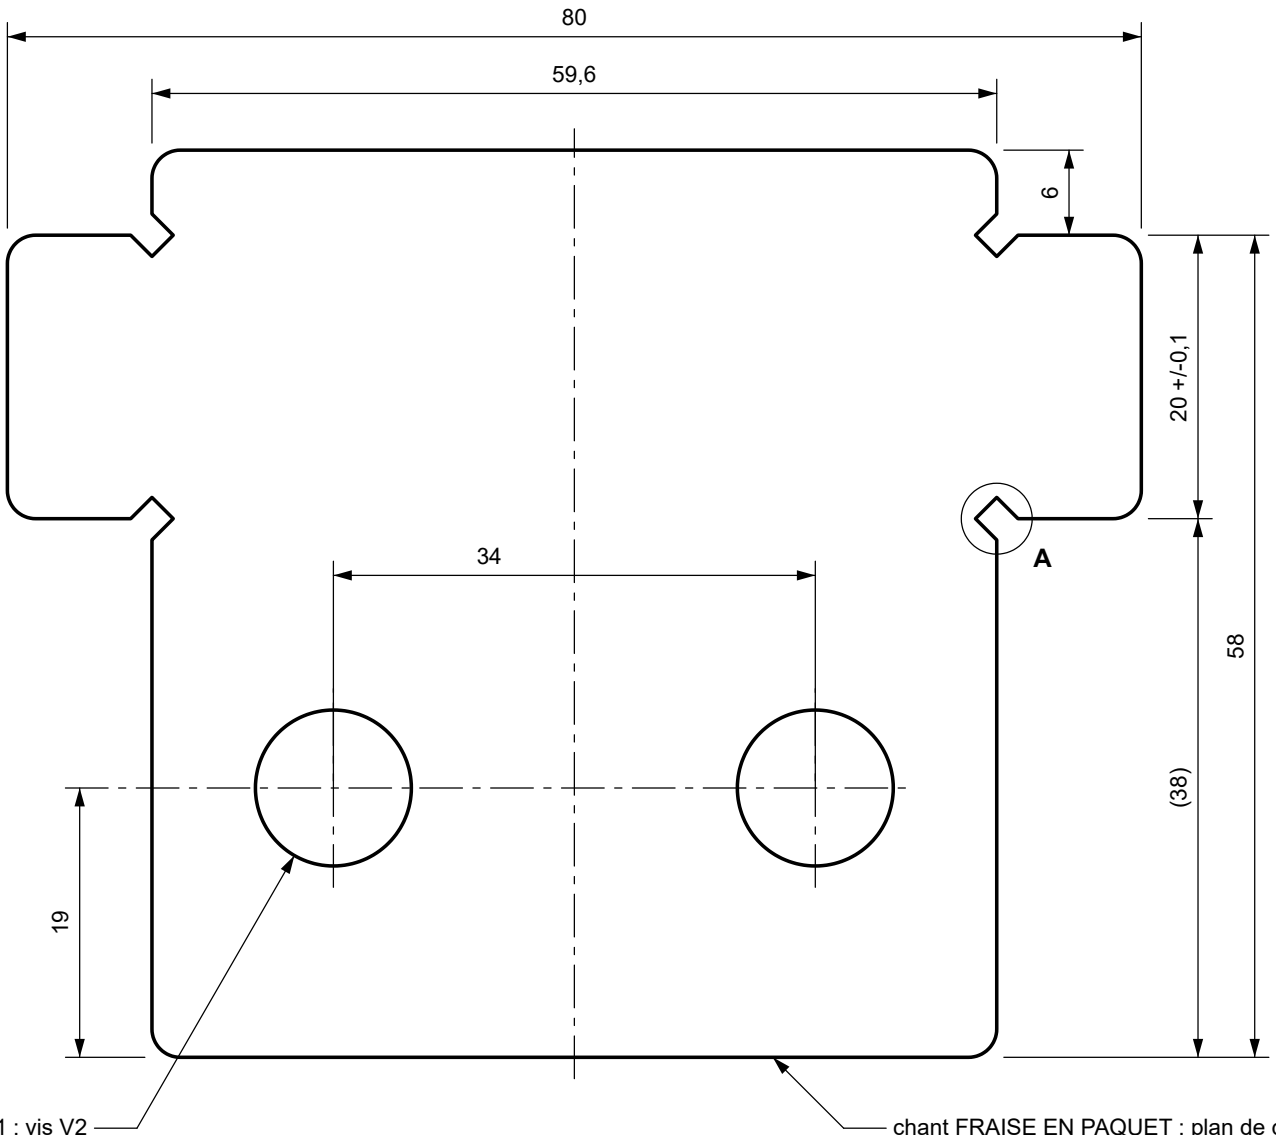
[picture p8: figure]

Matiere : S355JR, tole 8 mm du commerce : certificat 2.2 EN 10204 ; chant fraise frottant sur le bronze, sous pate graphite : admis a 7,6 MPa et a cette vitesse.

### 03 PLAQUE DE TRAVERSE, VUE SELON X (2:1)

ep. 8, 6 plaques identiques serrees en paquet

2 x diam. 11 : vis V2 | chant FRAISE EN PAQUET : plan de glissement

### DETAIL A (10:1)

pied de tenon, 4 par plaque (ici en bas a droite)

1,5

poche carree tournee a 45 deg, centree sur l angle vif fictif :
3 traits droits, jamais un conge (il deborderait de l epaulement)

Sous 12 kN (verification de dimensionnement) :
- matage du tenon sur l arete de mortaise : 26,5 MPa sur 38,4 x 5,9 par flanc (bords ebavures et degagement deduits) ;
- racine de tenon : 11,5 MPa sur 17 nets ; plaque (64 de haut, percee de 11, appuis a 68,5) : 7,6 MPa, majorant ;
- bronze 06c : 7,6 MPa sur 30 nets (5 joints dans ses 38) ; Re du S355JR a 150 C : 300 MPa.
MONTAGE : serrer le paquet sur V2, engager les tenons dans un flanc, chants fraises du cote du coin, puis presenter le second flanc.

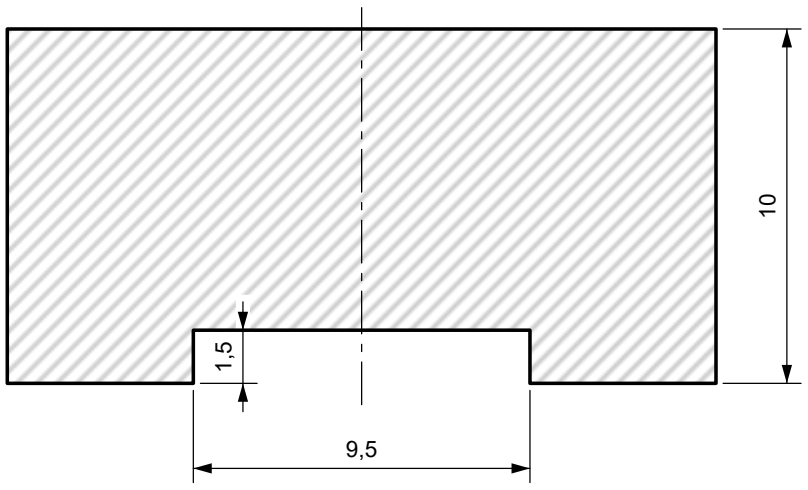
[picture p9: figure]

# PATIN D APPUI RAINURE

indice B
05/10/2026

## rep. 04a

matiere
S355JR

brut
tole 10 mm

quantite
4

1:1 - coupe 5:1

Un jeu neuf par eprouvette : 4 x 04a, 1 x 04b, 2 x 04c ; il part avec la poutrelle.

Surfaces a coller : poncer P80 et degraisser a l acetone. Colle Duralco 4420, post-cuisson selon la notice avant charge.

Collage (NOMENCLATURE.md, ordre de montage) : 04c etape 1, 04b etape 9 (centre au trace), 04a etape 13 ; polymeriser sous la precharge (etape 16).

04a : colle par sa face superieure seulement, contre le plat ; rainure SECHE sur le bossage, qui doit y basculer.

04a : le fond de rainure porte le bossage, 3 kN par patin (4 contacts, 2 par appui) : Hertz 339 MPa, limite 480 MPa a 150 C, coefficient 1,42 : S355JR au minimum.

04a : rainure 9,5 = tole REELLE du flanc (EP_TOLE_REELLE_42 = 8) + 2 x 0,75 de jeu : mesurer la tole 42CrMo4 livree et regenerer ce plan.

04a : decoupe laser d apres patin_appui.dxf (calque DECOUPE), PUIS rainure fraisee sur toute la longueur de la face d appui.

Aretes des patins et du plat ebavurees, sans chanfrein.

### 04a PATIN D APPUI RAINURE, VUE DE DESSOUS (1:1)

S355JR, 4 ex., brut tole 10 mm

90

20

A 4 x R3

A

### COUPE A-A (5:1)

face collee en haut, rainure cote bossage

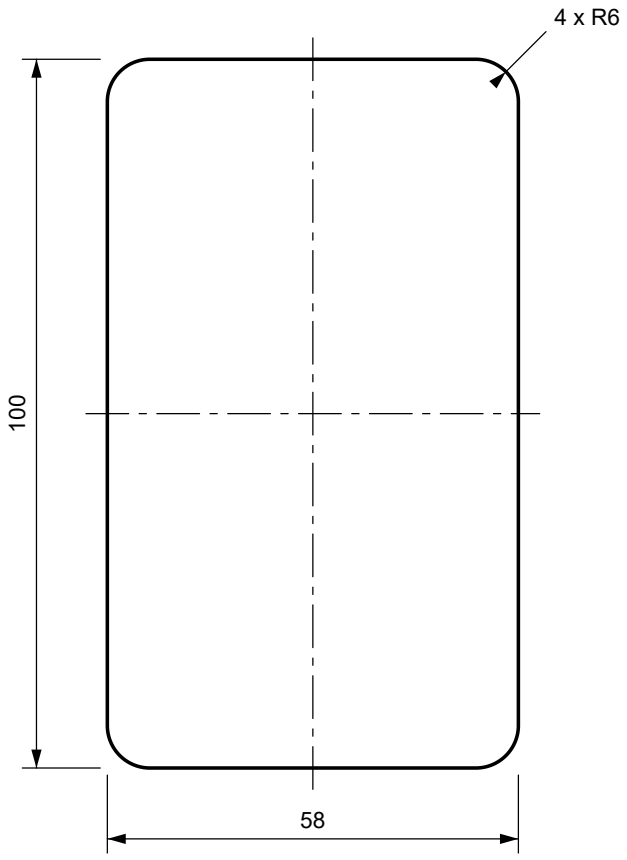
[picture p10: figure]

# PATIN DE CHARGE BOMBE

indice B
05/10/2026

## rep. 04b

matiere
S355JR

brut
tole 10 mm

quantite
1

Un jeu neuf par eprouvette : 4 x 04a, 1 x 04b, 2 x 04c ; il part avec la poutrelle.

Surfaces a coller : poncer P80 et degraisser a l acetone. Colle Duralco 4420, post-cuisson selon la notice avant charge.

Collage (NOMENCLATURE.md, ordre de montage) : 04c etape 1, 04b etape 9 (centre au trace), 04a etape 13 ; polymeriser sous la precharge (etape 16).

04b : decoupe d apres patin_charge.dxf, SANS TROU, PUIS dessus bombe fraise. Sa longueur 58 laisse passer les tetes des vis du poussoir (02b a 3,5 de ses bouts) ; 2,07 MPa sur le beton a 12 kN.

Aretes des patins et du plat ebavurees, sans chanfrein.

### 04b PATIN DE CHARGE, epaisseur 10 (1:1)

S355JR, 1 ex., brut tole 10 mm

10

9,58

dessus bombe R1000
dessous plat, colle

# PLAT DE RENFORT COLLE

indice B
05/10/2026

## rep. 04c

matiere
S235

brut
feuillard 20 x 2

quantite
2

Un jeu neuf par eprouvette : 4 x 04a, 1 x 04b, 2 x 04c ; il part avec la poutrelle.

Surfaces a coller : poncer P80 et degraisser a l acetone. Colle Duralco 4420, post-cuisson selon la notice avant charge.

Collage (NOMENCLATURE.md, ordre de montage) : 04c etape 1, 04b etape 9 (centre au trace), 04a etape 13 ; polymeriser sous la precharge (etape 16).

Piece du commerce : feuillard 20 x 2 coupe a longueur, angles vifs, ebavure ; pas de DXF.

### 04c PLAT DE RENFORT (1:5)

S235, 2 ex., piece du commerce : feuillard 20 x 2 coupe a longueur, angles vifs ; pas de DXF

840

colles sous la poutrelle, un dans l axe de chaque flanc : entraxe 68, centres sur la poutrelle, bord exterieur a 7,5 du bord de la poutrelle (planche 00, coupe A-A)

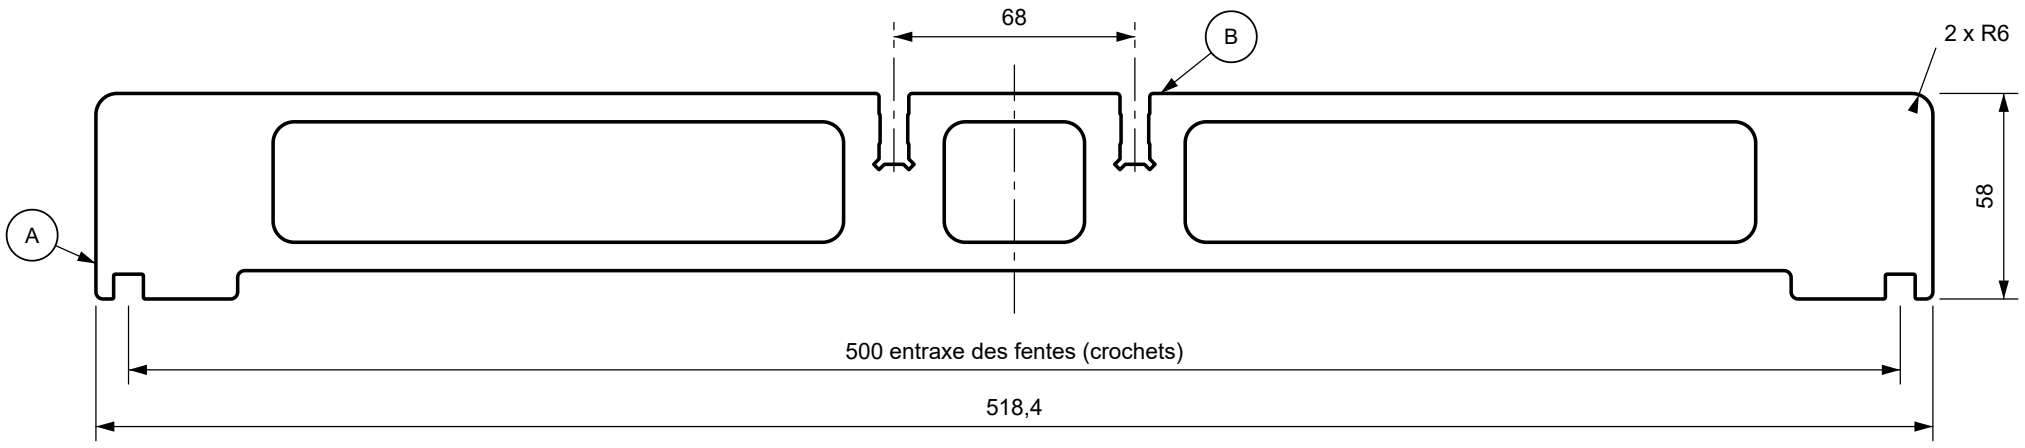
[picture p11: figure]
500 entraxe des fentes (crochets)

# PIED A MI-BOIS

indice B
05/10/2026

## rep. 05

matiere
S355JR

brut
tole 8 mm, cert. 2.2

quantite
4

1:2 - details 2:1

Mesurer les deux toles livrees, regler EP_TOLE_REELLE_42 (42CrMo4) et EP_TOLE_REELLE_S355 (S355JR) et regenerer les DXF avant decoupe.

05 : fentes de calage a +/- 250 de l axe (entraxe 500) : crochets a 14,2 des parois laterales, colonnes de trous confirmees.

05 : l encoche (20) porte fond sur fond dans celle du flanc (8, planche 01, detail W) ; plan de pose a 30 sous le chant du flanc.

05 : 2 sous le chant bas des flancs (couche), 2 en V aux coins de l about a 38 deg (debout), aretes de pose a 447.

05 : fentes de calage 8,4 = e' + 2 x 0,2, e' = tole REELLE du crochet S355 (EP_TOLE_REELLE_S355 = 8).

05 : encoches 8,4 = e + 0,4 et passage aux nodes 7,8 = e - 2 x 0,1 (serrage), e = tole REELLE du flanc 42CrMo4 (EP_TOLE_REELLE_42 = 8) ;

Matiere : S355JR, tole 8 mm du commerce : certificat 2.2 EN 10204.

Decoupe laser d apres pied.dxf (calque DECOUPE) ; aretes ebavurees, sans chanfrein.

### 05 PIED A MI-BOIS (1:2)

S355JR, 4 ex., brut tole 8 mm, cert. 2.2

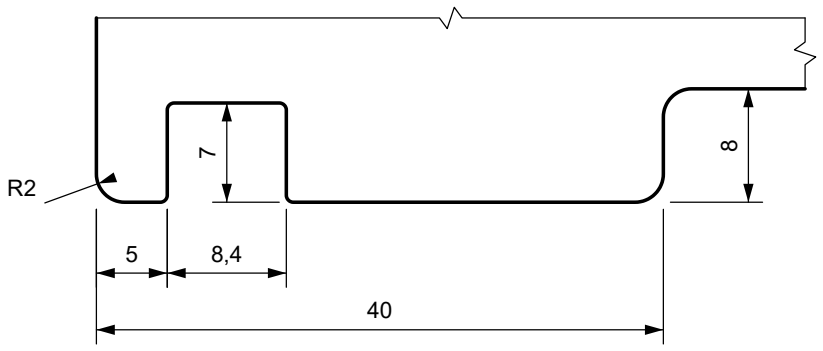
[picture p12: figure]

AJOURS DU PIED 05 (angles R6)
ajour | nb | y de | y a | z de | z a
central | 1 | -19,8 | 19,8 | 16 | 50
exterieurs | 2 | +/-48,2 | +/-209,2 | 16 | 50

y depuis l axe du pied, z depuis le plan de pose (dessous des bossages)

### DETAIL A (2:1)

bout du pied, 2 ex. symetriques fente : angles R0,5 ; bossage : R2 ; R2 du bout = arete de pose

### DETAIL B (2:1)

encoche, 2 ex. : un node par joue

8,4

7,8
20

6 8

angles du fond : poche carree de 2,1 tournee a 45 deg, centree sur l angle vif (3 traits) ; entree R1
nodes : rampes a 45 deg

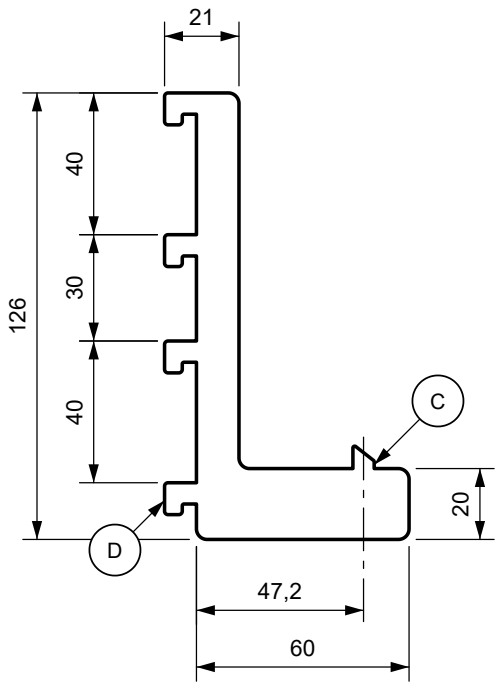
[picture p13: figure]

# CROCHET D ETUVE

indice B
05/10/2026

## rep. 05c

matiere
S355JR

brut
tole 8 mm, cert. 2.2

quantite
4

1:2 - details 2:1 et 5:1

Mesurer les deux toles livrees, regler EP_TOLE_REELLE_42 (42CrMo4) et EP_TOLE_REELLE_S355 (S355JR) et regenerer les DXF avant decoupe.

05c : angles du corps et de l appui R3 ; langues R1, fond de gorge R0,5 ; haut de la dent R0,5.

05c : pend par 4 langues a bec dans les trous carres de 10 (pas 40 / 30) de la paroi de 1, qui passe dans la gorge ; la dent cale le pied.

Matiere : S355JR, tole 8 mm du commerce : certificat 2.2 EN 10204.

Decoupe laser d apres crochet.dxf (calque DECOUPE) ; aretes ebavurees, sans chanfrein.

### 05c CROCHET D ETUVE (1:2)

S355JR, 4 ex. ; y = 0 : face interieure de la paroi dent a 47,2 de la paroi : etuve de 538 confirmee

### DETAIL D (2:1)

langue, 4 ex. identiques

9

9

3 4

### DETAIL C (5:1)

dent de l appui, haute cote paroi
dessus a 38 deg, comme le fond de fente du pied en V

6

6,84

2,16

### 06a TOURILLON (2:1)

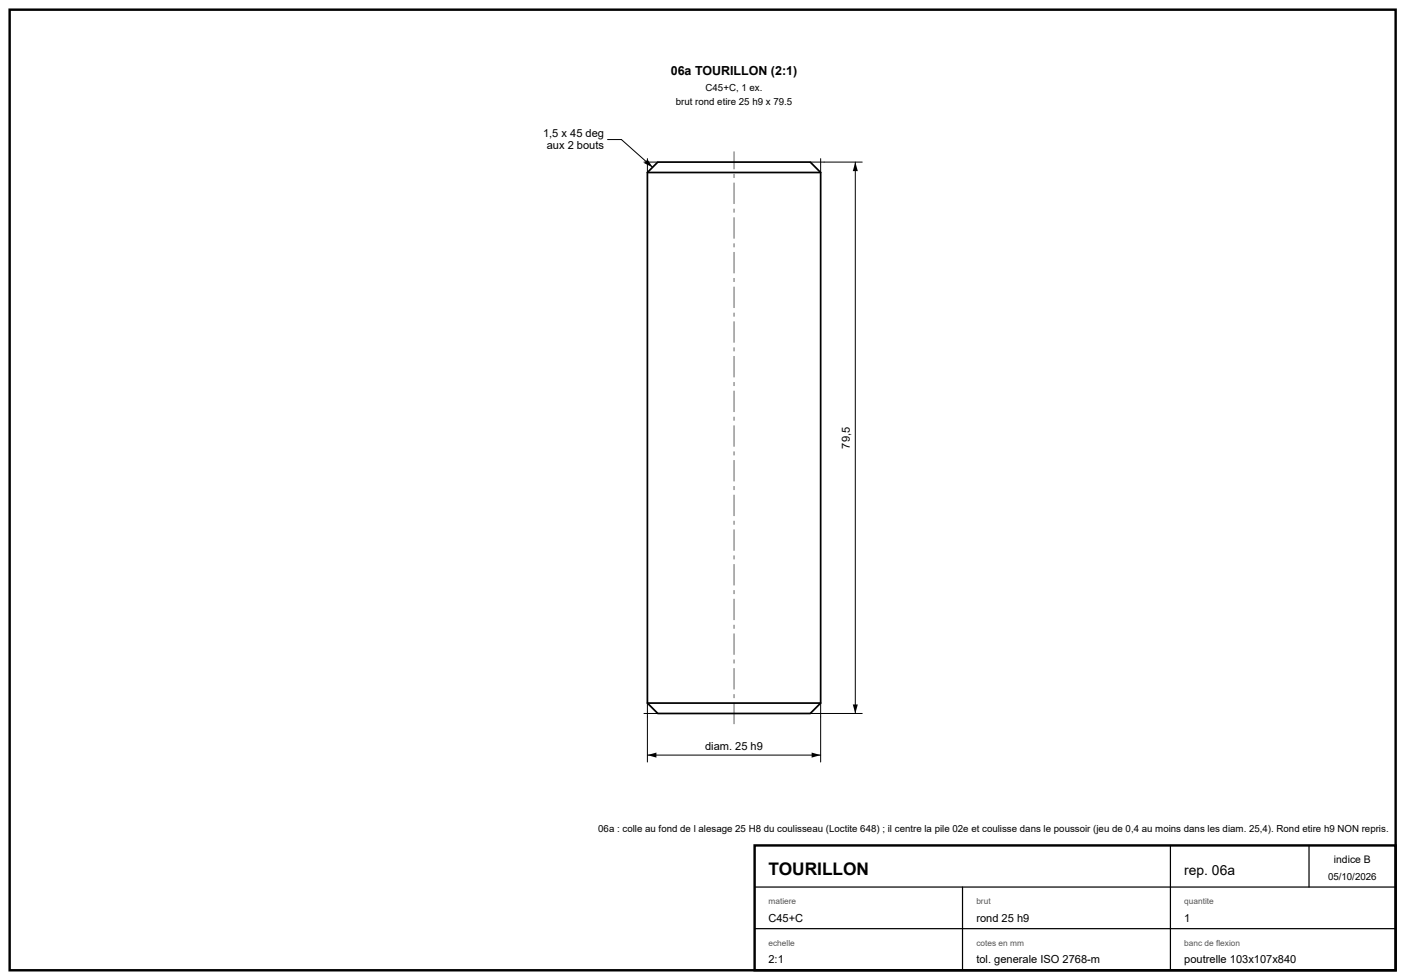
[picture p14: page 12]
TOURILLON; indice B; rep. 06a; matiere C45+C; brut rond 25 h9; quantite 1; diam. 25 h9; 1,5 x 45 deg aux 2 bouts

brut rond etire 25 h9 x 79.5

06a : colle au fond de l alesage 25 H8 du coulisseau (Loctite 648) ; il centre la pile 02e et coulisse dans le poussoir (jeu de 0,4 au moins dans les diam. 25,4). Rond etire h9 NON repris.

### 06b ENTRETOISE DE CADRE, COUPE AXIALE (2:1)

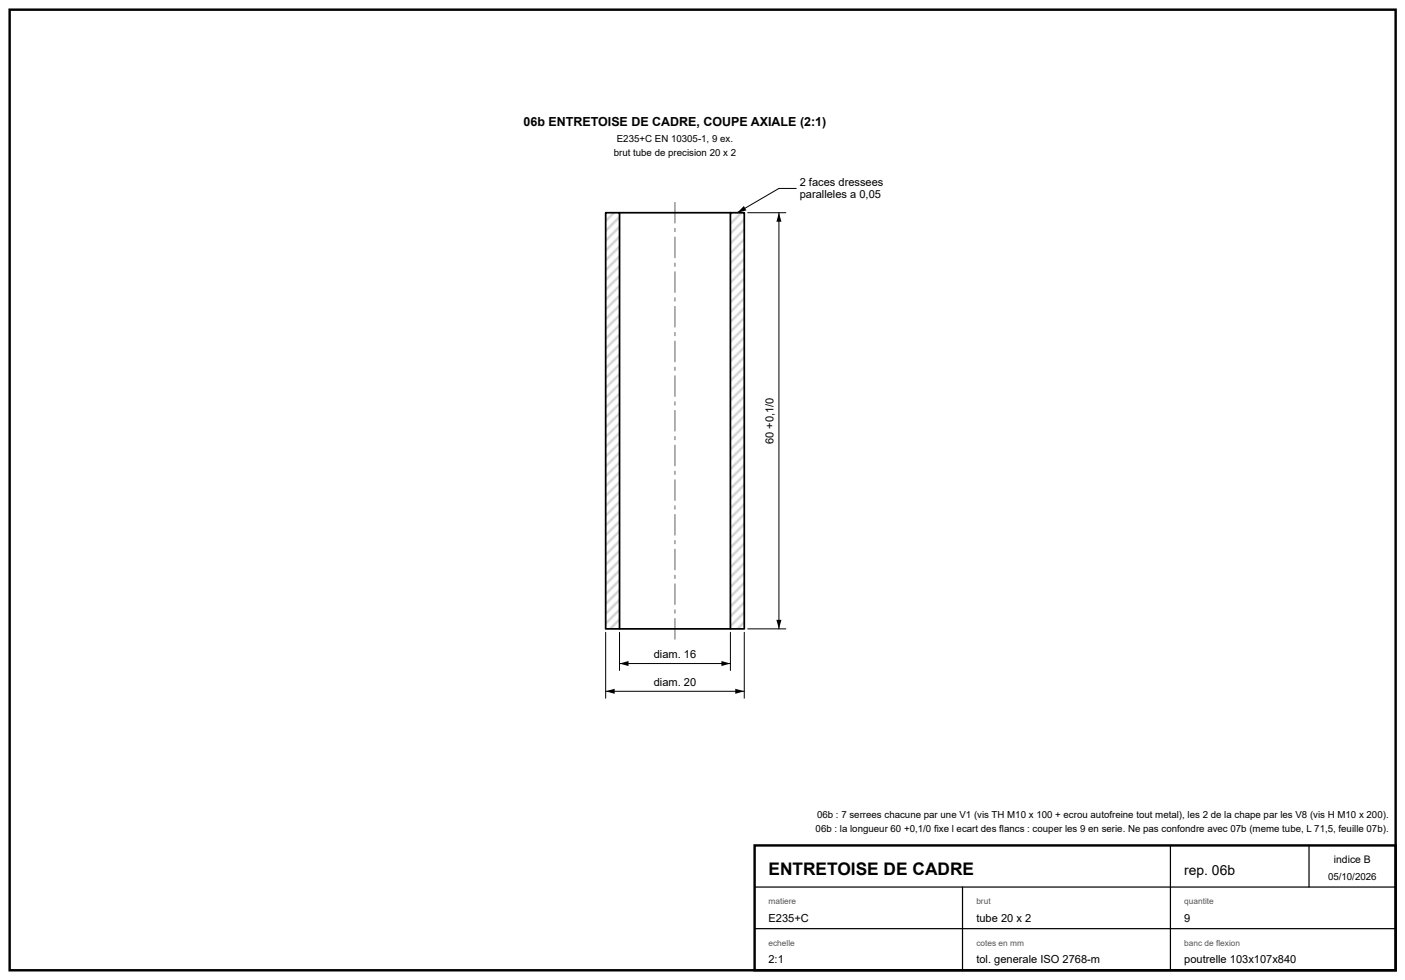
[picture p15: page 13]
indice B; rep. 06b; matiere E235+C; brut tube 20 x 2; quantite 9; diam. 16; diam. 20; 2 faces dressees paralleles a 0,05

brut tube de precision 20 x 2

06b : 7 serrees chacune par une V1 (vis TH M10 x 100 + ecrou autofreine tout metal), les 2 de la chape par les V8 (vis H M10 x 200).
06b : la longueur 60 +0,1/0 fixe l ecart des flancs : couper les 9 en serie. Ne pas confondre avec 07b (meme tube, L 71,5, feuille 07b).
ENTRETOISE DE CADRE

### 06c PLAQUE DE FROTTEMENT, DESSUS DU COIN (1:1)

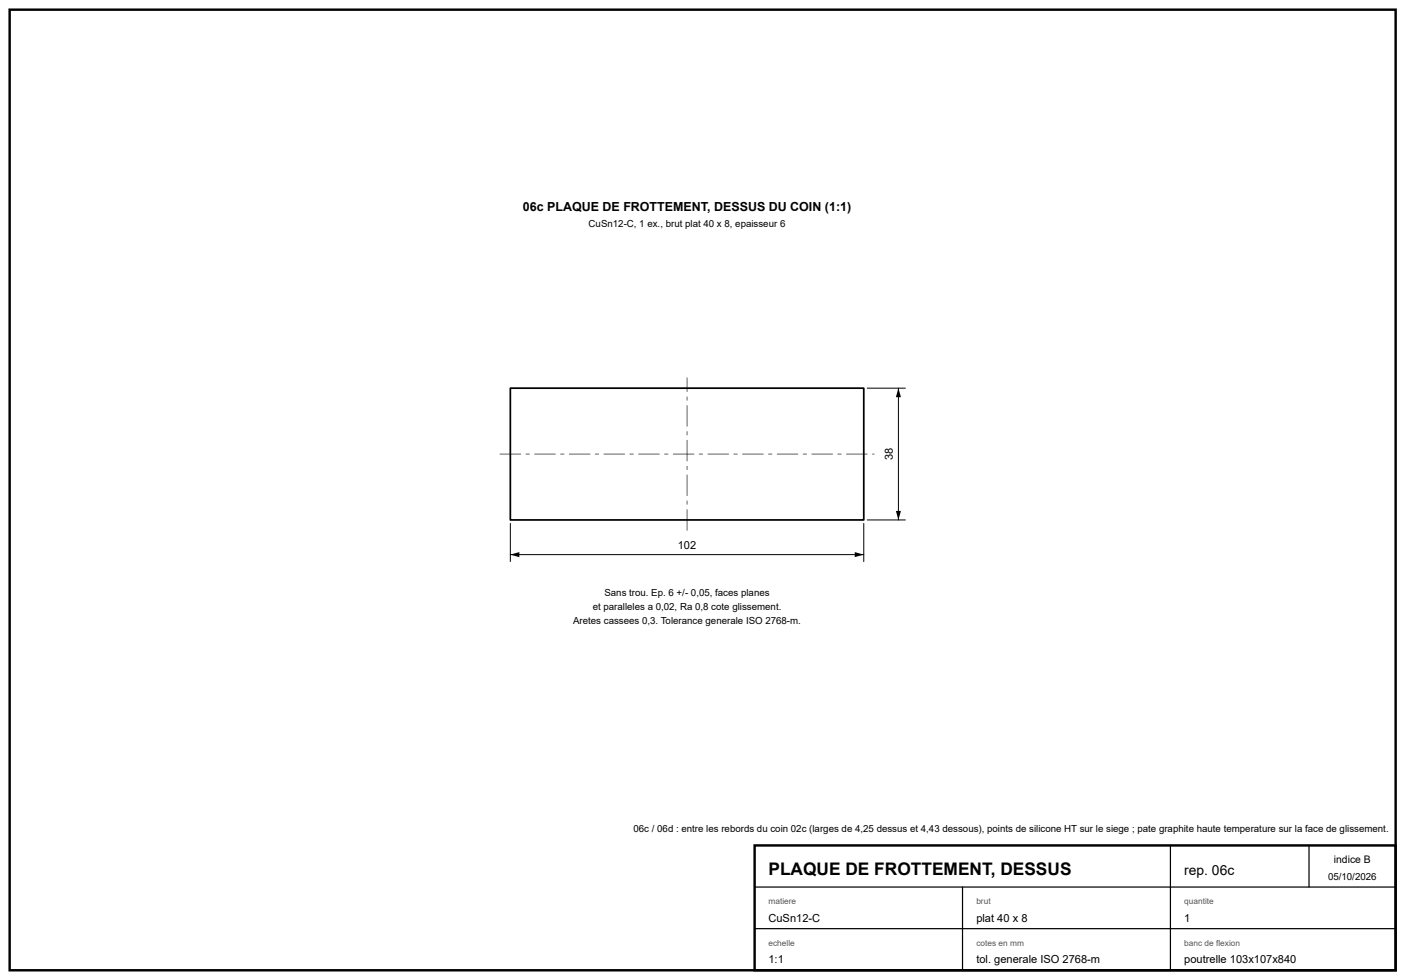
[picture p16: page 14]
indice B; rep. 06c; matiere CuSn12-C; brut plat 40 x 8; quantite 1

CuSn12-C, 1 ex., brut plat 40 x 8, epaisseur 6

Sans trou. Ep. 6 +/- 0,05, faces planes
et paralleles a 0,02, Ra 0,8 cote glissement.
Aretes cassees 0,3. Tolerance generale ISO 2768-m.

06c / 06d : entre les rebords du coin 02c (larges de 4,25 dessus et 4,43 dessous), points de silicone HT sur le siege ; pate graphite haute temperature sur la face de glissement.

PLAQUE DE FROTTEMENT, DESSUS

### 06d PLAQUE DE FROTTEMENT, DESSOUS DU COIN (1:1)

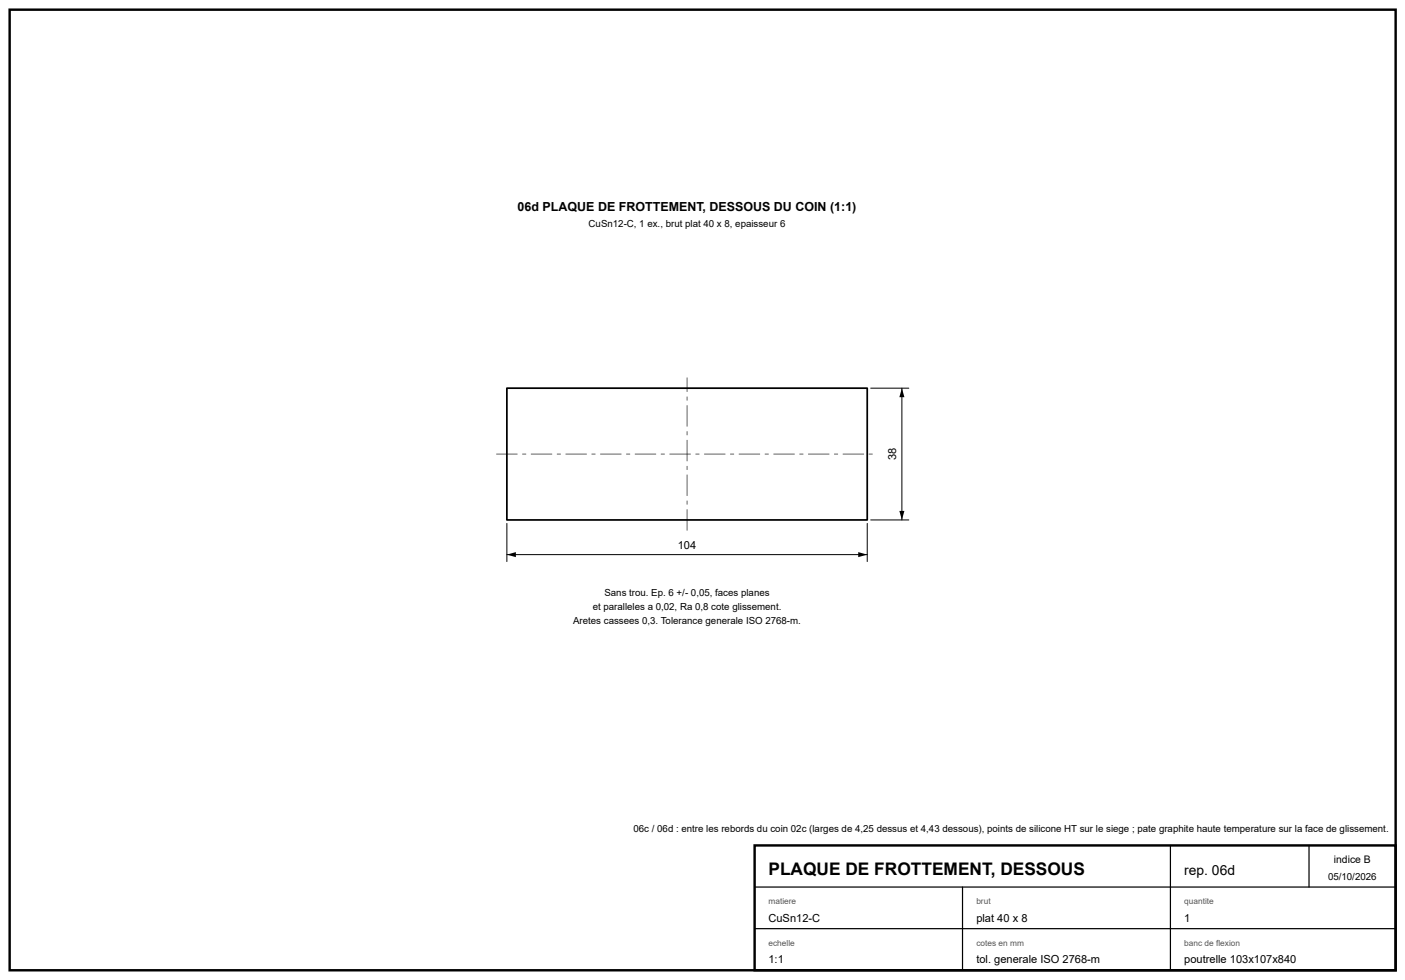
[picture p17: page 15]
indice B; rep. 06d; matiere CuSn12-C; brut plat 40 x 8; quantite 1

CuSn12-C, 1 ex., brut plat 40 x 8, epaisseur 6

Sans trou. Ep. 6 +/- 0,05, faces planes
et paralleles a 0,02, Ra 0,8 cote glissement.
Aretes cassees 0,3. Tolerance generale ISO 2768-m.

06c / 06d : entre les rebords du coin 02c (larges de 4,25 dessus et 4,43 dessous), points de silicone HT sur le siege ; pate graphite haute temperature sur la face de glissement.

PLAQUE DE FROTTEMENT, DESSOUS

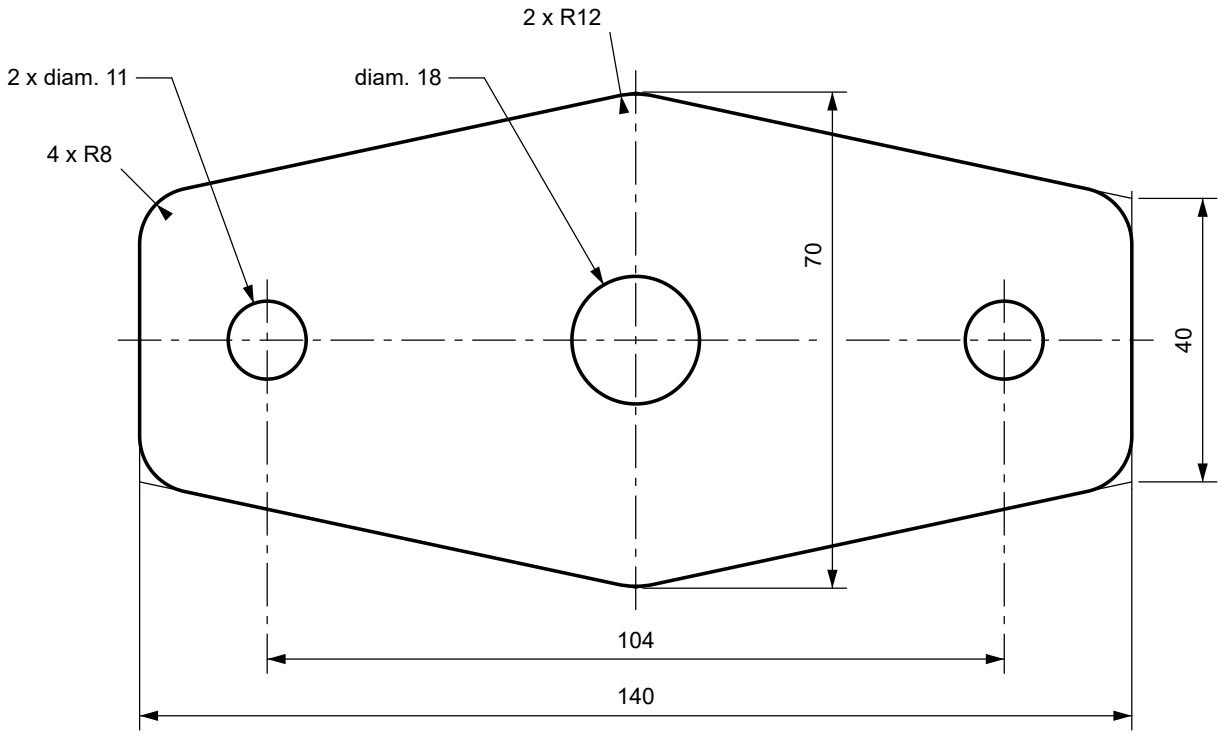
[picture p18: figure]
2 x diam. 11; diam. 18

# PLATINE DE BUTEE

indice B
05/10/2026

## rep. 07

matiere
42CrMo4 +A, Re >= 430

brut
tole 8 cert.3.1

quantite
2

Platine : 130 MPa en flexion, coefficient 3,3 a 20 C et 3,0 a 150 C, fleche 0,14 mm.

07 : decoupe laser d apres support.dxf, aretes ebavurees ; 40 et 70 entre aretes fictives (au sommet R12, la tole mesure 69,46).

07 : 42CrMo4 recuit +A, tole 8 mm : certificat 3.1 EN 10204 avec essai de traction, Re >= 430 MPa a 20 C ; meme tole que les flancs, platines imbriquees dans leurs chutes.

### 07 PLATINE DE BUTEE (1:1)

42CrMo4 +A, 2 ex. identiques, empilees brut tole 8 mm, cert. 3.1, Re >= 430

### 07b ENTRETOISE DE BUTEE, COUPE AXIALE (2:1)

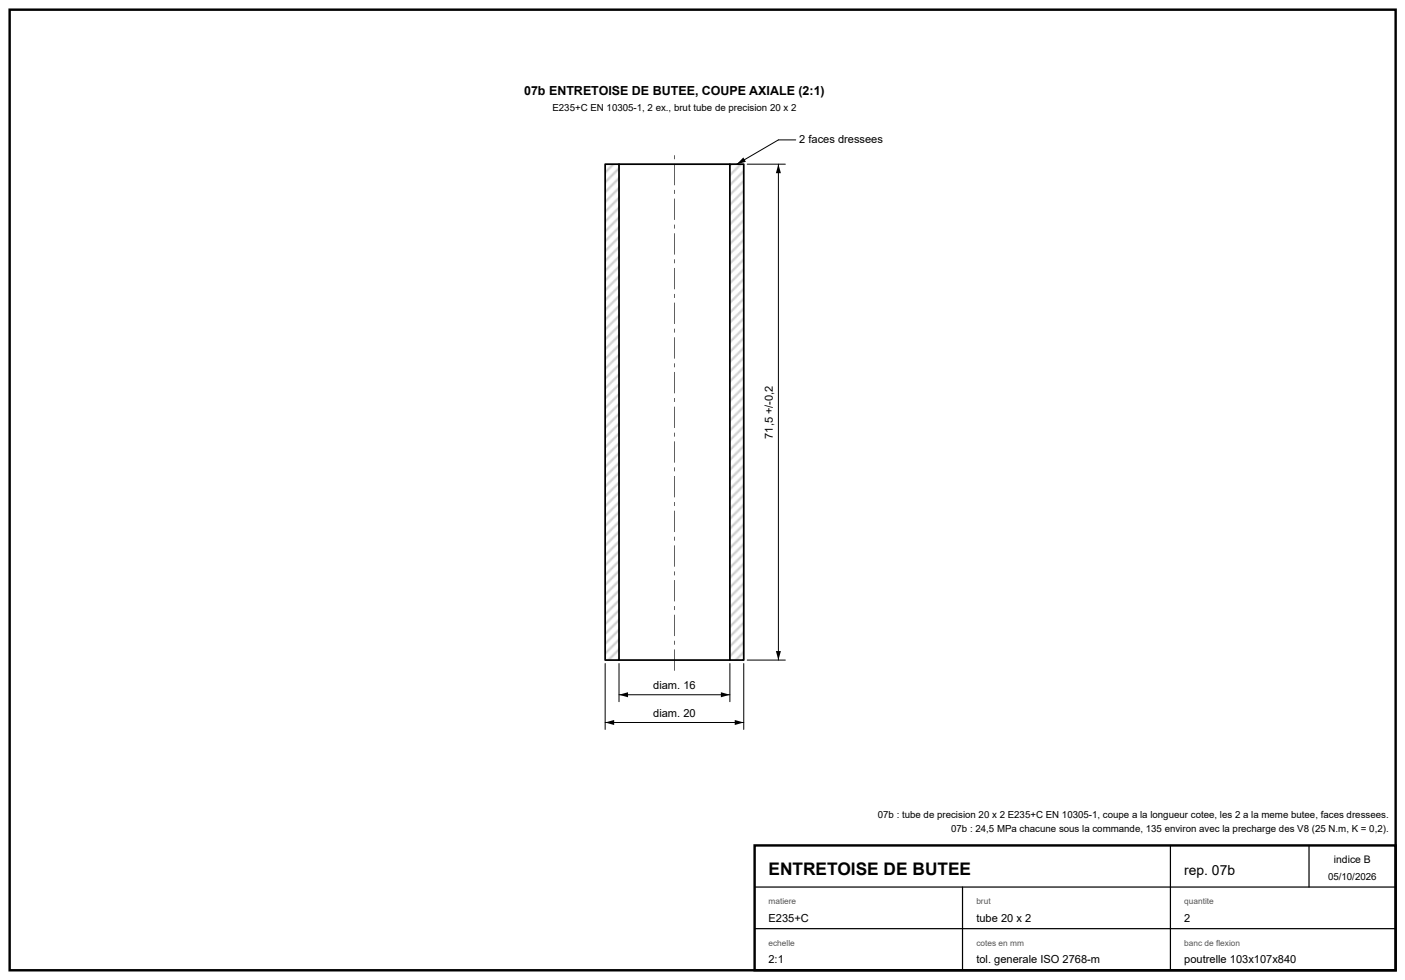
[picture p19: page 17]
indice B; rep. 07b; matiere E235+C; brut tube 20 x 2; quantite 2; diam. 16; diam. 20; 2 faces dressees

E235+C EN 10305-1, 2 ex., brut tube de precision 20 x 2

07b : tube de precision 20 x 2 E235+C EN 10305-1, coupe a la longueur cotee, les 2 a la meme butee, faces dressees.

07b : 24,5 MPa chacune sous la commande, 135 environ avec la precharge des V8 (25 N.m, K = 0,2).

ENTRETOISE DE BUTEE

# MONTAGE DE LA CHAPE

indice B
05/10/2026

## rep. 07m

matiere
voir nomenclature

brut

quantite
1 ensemble

V7 : 0,1 a 0,3 de jeu axial, puis contre-bloques. Tete de 02d : douille de 24 et cliquet, une cle plate bute sur les V8.

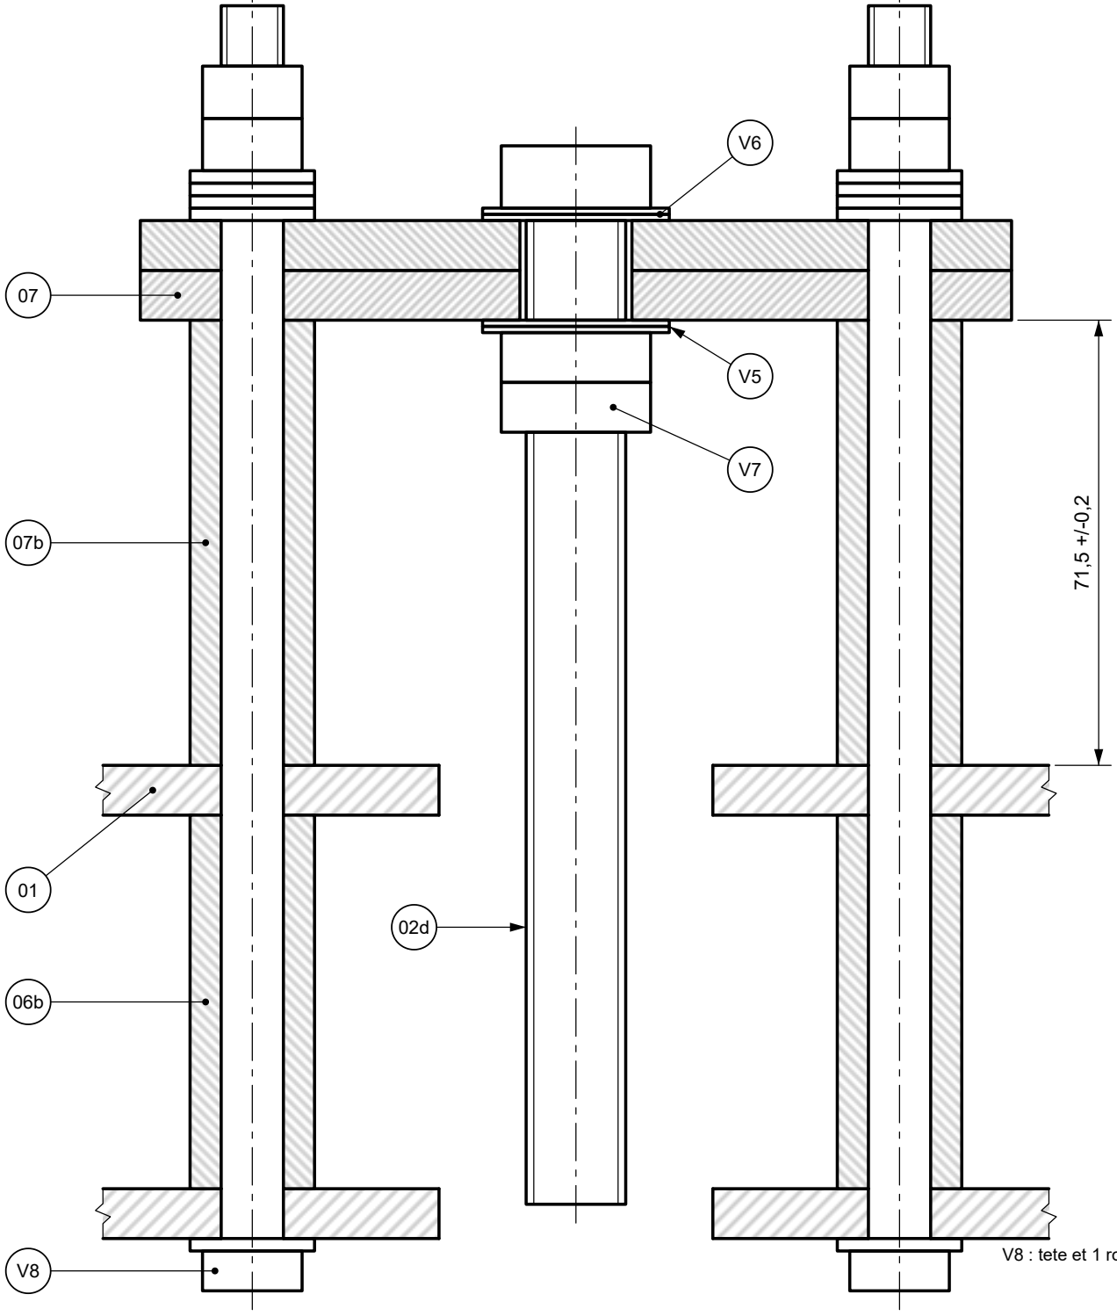
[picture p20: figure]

V8 : tete et 1 rondelle derriere le flanc oppose, 4 rondelles et 2 ecrous H cote platines ; le premier sur le filet (marge 5,5), 25 N.m, puis le contre-ecrou bloque contre lui.

Commande 5,5 kN : le coin tire la vis, sa tete pousse les rondelles V6 ; platines et 07b comprimees ; V8 : 329 N au desserrage.

### MONTAGE DE LA CHAPE, COUPE PAR LES AXES (1:1)

vue de dessus, butee vers le haut ; coin et tete de charge non representes jeu des V8 dans leurs trous non represente (trous de 11, vis de 10)

Pieces du montage
rep. | designation | qte
01 | flanc (feuille 01) | 2
06b | entretoise de cadre, L 60 (feuille 06b) | 2
07b | entretoise de butee, tube 20 x 2 (feuille 07b) | 2
07 | platine de butee (feuille 07) | 2
02d | vis H M16 x 160 ISO 4017, filetage total | 1
V5 | rondelle trempee AS 1730 (17 x 30 x 1) | 2
V6 | rondelle trempee AS 1730, sous la tete | 2
V7 | ecrou M16 HM ISO 4035 | 2
V8 | vis H M10 x 200 + 2 ecrous + 5 rondelles | 2

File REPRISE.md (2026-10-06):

# Reprise

Etat au 06/10/2026, indice B. `python make.py` se termine par
« termine, 0 etape(s) en echec ». La derniere relecture complete des planches
est dans `revue_finale/BILAN.md` (constats contre-verifies dans
`revue_finale/constats/`).

## Decisions encore ouvertes, pour l'utilisateur

- Tourillon en C45+C etire h9 (choix actuel) ou S355JR : `TOURILLON_MATIERE`.
- V5 : 2 rondelles AS 1730 a la place d'une rondelle trempee 30 x 2 (introuvable en M16).
- Centrage selon x du paquet de traverse dans sa mortaise.
- Hauteur d'etuve 1400 a confirmer (largeur 538 confirmee le 05/10/2026).
- Calage de la poutrelle en position debout : point ouvert assume.
- Points D-09, C-04, C-05, D-08 de `revue_finale/BILAN.md`.

## Environnement

- Python 3 avec Pillow et openpyxl : `pip install pillow openpyxl`.
- Rendu des planches et PDF : Chrome / Edge / Chromium sans interface ;
  `outils.py` le trouve seul, ou par la variable `BANC_NAVIGATEUR`.
- Modele 3D et controle d'interference : FreeCAD 1.0 (`freecadcmd`), variable
  `BANC_FREECAD` si hors du chemin habituel. Sans FreeCAD, tout le reste
  tourne : `params.py`, `verif_percages.py`, `plans.py`, `verif_plans.py`,
  `spec.py`, `nomenclature.py`, `export_dxf.py`.
- Les calculs EF (`fem_*.py`) ne sont pas a relancer tant que la geometrie du
  flanc ne change pas (213 MPa, coefficient 2,02 / 1,83 ; flambement 38,2 /
  38,3 avec les entretoises 20 x 2). Leurs dossiers de travail (`out/fem`,
  `out/flamb*`, plusieurs centaines de Mo) sont recrees au besoin ; seuls les
  resultats `out/fem_flanc.json` et `out/flambement*.json` sont gardes.

## Pieges connus

- Dans `spec.py`, l'accumulateur du document s'appelle `L` : ne jamais creer
  de variable locale `L`, cela vide SPEC.md sans erreur.
- Certains fichiers sont en CRLF : conserver les fins de ligne.
- `params.py` et `verif_interference.py` rendent 0 meme en cas de probleme :
  seul leur bilan imprime fait foi, et `make.py` l'exige.

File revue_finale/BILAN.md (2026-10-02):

# Relecture finale du 02/10/2026 : bilan

Six relecteurs independants :
- 8 planches, deux lentilles chacune (cotes, lisibilite) ;
- changements de conception du 02/10 ;
- coherence entre documents.

Leurs constats sont dans `constats/*.json`. Chacun a ete contre-verifie avant
correction. Apres corrections : `params.py` 0 probleme, `verif_percages.py`
0 faute, `verif_plans.py` 777 textes, 0 faute.

## Corrige

| constat | correction |
|---|---|
| outillage | `verif_plans.py` voit tout trait (fins, arcs, cercles, cadres) contre la boite ORIENTEE des textes, chasses Helvetica reelles |
| outillage | `rendu_planches.py` : PNG de la feuille entiere (ils s'arretaient a 274 mm) |
| 00-04, D-02 | dates et empreinte du modele ecrites DANS les JSON de resultat : plus de faux « PERIME », dates de flambement justes, paragraphe du balayage conserve |
| 00-01 (bulle 01), 00-02 | reperes de l'assemblage hors des fenetres et des hachures |
| 01-01, 01-02, 01-04 | bulle C, entraxe 500 sur axes, loi de la mortaise |
| 02-01, 02-02 | degagement du detail C, appels B et C |
| 03-01 | noms de variables retires de la planche |
| 04-01, 04-02 | entraxe 70 sur axes ; 3 kN par patin (et par bossage sur la 01) |
| 06-01, 06-02, 06-03 | aretes de l'alesage, angles vifs fictifs, note 4 |
| 07-01 | hachures des deux platines differenciees |
| D-01, D-04 a D-07, D-11 a D-13 | README (Linux, outils), DEBOUT, arrondis, support.dxf, ISO 2338 |

## Laisse en l'etat, motive

- **00-01, V9 et 02f** : la ligne de repere traverse l'arete du lobe. Les
  bulles n'ont pas de place dans le lobe sans croiser une lumiere.
- **00-03 et 01-05** : echelles 1:2,5 et 1,5:1, justes et annoncees.
  Elles sont admises par l'ISO 5455 comme echelles d'exception ; a 1:2 ou
  2:1, la vue ne tient pas.
- **01-03** : trois cotes de detail posees dans la matiere. Une cote dans
  la matiere est admise quand elle est plus claire, et dehors elle
  croiserait d'autres traits.

## Tranche par l'utilisateur et applique

- **C-01** : crochet, langue 6 + bec 3 (tete de 9 dans le trou de 10), pose de
  face puis descente ; nouveau controle dans `verifie()`.
- **C-02** : V2 en M10 x 90, V9 avec 4 rondelles sous l'ecrou. `verifie()`
  passe de 7,25 a 9,2 mm de tole mesuree.
- **C-03 et D-03** : hauteurs ISO. Ecrou H M10 ISO 4032 = 8,4 ; tete V7 =
  22,8 (ISO 4032 + ISO 4035 M16). La tige depasse desormais de 2,7 de la tete
  (plus d'un pas).
- **D-10** : V9 freinee par un contre-ecrou H ISO 4032 (2 ecrous H, le second
  bloque contre le premier), tout metal. M10 x 200 conservee : la vis depasse
  du contre-ecrou de 4,9 a 12,7 sur toute la tolerance de tole. Une vis plus
  longue a filetage partiel (ISO 4014) ne conviendrait pas : son filet
  commencerait au-dela de l'empilement.

## A trancher

- **D-09** : 12,6 MPa (SPEC, DEBOUT) contre 92 MPa avec precharge
  (planche 07). Le controle de `verifie()` ne compte que les 12,6.
- **C-04** : la note de traverse donne 64 / 38 ; depuis les faces hautes
  des tenons, la cote vaut 58 (comme sur la planche 03).
- **C-05** : deux controles de `verifie()` sont toujours vrais par
  construction.
- **D-08** : pate graphite ou cuivre sur la tige. L'irreversibilite du
  filet n'est chiffree que pour la pate cuivre.
- **Decisions de REPRISE.md, toujours ouvertes** :
  - tourillon (C45 ou S355) ;
  - rondelles V5 ;
  - couple de serrage M10 ;
  - centrage de la traverse (constat 03-11) ;
  - largeur d'etuve 540 ;
  - calage de la poutrelle en position debout.
- **Non relance ici** : FreeCAD n'est pas installe dans la session cloud.
  Le modele 3D et le controle d'interference n'ont pas ete relances, mais
  `params.py` et `parts.py` sont inchanges.

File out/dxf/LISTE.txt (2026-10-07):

DXF de decoupe, ind. B du 05/10/2026
toles reelles : 42CrMo4 8,00 mm (EP_TOLE_REELLE_42), S355JR 8,00 mm (EP_TOLE_REELLE_S355) : mesurer les deux toles livrees, regler EP_TOLE_REELLE_42 (42CrMo4) et EP_TOLE_REELLE_S355 (S355JR) et regenerer les DXF avant decoupe
Fentes, encoches et mortaises : chacune suit la tole qu elle RECOIT (flanc : tole S355JR ; pied : 42CrMo4 pour les encoches et nodes, S355JR pour les fentes).
calques : DECOUPE = couper ; GRAVURE = marquer sans couper ; TEXTE = ni couper ni marquer
Pieces du commerce, sans DXF : guide, vis, plat_renfort, pile_belleville.

fichier                               ep  matiere       qte  statut
flanc.dxf                              8  42CrMo4 +A      2  a decouper
traverse.dxf                           8  S355JR          6  a decouper (brut, reprise)
poussoir.dxf                           8  S355JR          3  a decouper
support.dxf                            8  42CrMo4 +A      2  a decouper
patin_appui.dxf                       10  S355JR          4  a decouper
patin_charge.dxf                      10  S355JR          1  a decouper
pied.dxf                               8  S355JR          4  a decouper
crochet.dxf                            8  S355JR          4  a decouper
tole_8mm_42crmo4.dxf                   8  42CrMo4 +A      4  groupe a decouper : flanc, support ; 1 etagere(s), 2275 x 440
tole_8mm_s355.dxf                      8  S355JR         17  groupe a decouper : traverse, poussoir, pied, crochet ; 2 etagere(s), 2611 x 224
tole_10mm_s355.dxf                    10  S355JR          5  groupe a decouper : patin_appui, patin_charge ; 1 etagere(s), 518 x 100

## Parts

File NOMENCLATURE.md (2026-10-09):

# Banc de flexion 3 points - nomenclature

Indice B du 05/10/2026. Fichier engendre par `nomenclature.py` ; ne pas le modifier a la main.

Poutrelle beton non arme 103 x 107 x 840, portee 750, capacite 12 kN.

Encombrement des flancs 960 x 440 x 76 mm ; selon y, de -85,5 (coin recule) a +160 (bout des vis de chape), soit 245,5 ; pieds de 518.4.

## Exigences de commande

- **Tole de 8 en 42CrMo4** (flancs, platines de butee imbriquees dans les chutes des flancs) : 42CrMo4 recuit +A, tole 8 mm : certificat 3.1 EN 10204 avec essai de traction, Re >= 430 MPa a 20 C. C est elle qui porte toute la marge du flanc. Les cartouches et la colonne brut l abregent en "tole 8 mm, cert. 3.1, Re >= 430".
- **Tole de 8 en S355JR** (pieds, crochets, plaques de traverse, plateaux du poussoir) : S355JR, tole 8 mm du commerce : certificat 2.2 EN 10204, sans autre exigence ; abregee en "tole 8 mm, cert. 2.2". Ces pieces travaillent a quelques dizaines de MPa au plus (traverse 8 MPa en flexion et 26 au matage).
- **Finition des flancs** : apres decoupe et ebavurage : SABLAGE corindon des deux faces a l identique, pression moderee (planeite), puis BRUNISSAGE noir (oxydation a chaud), aspect mat ; degraisser l huile de sortie de bain, puis film d huile ESTER synthetique haute temperature passe au chiffon et ESSUYE ; ni huile minerale ni silicone ; graduation gravee a 0.2 de profondeur au moins, traits repasses a la peinture blanche haute temperature apres brunissage. Noir mat pour la correlation d images, et quasi sans epaisseur : ni les jeux des encoches ni les serrages des entretoises n en dependent. Les autres pieces restent brutes.
- **Epaisseurs reelles** : mesurer les deux toles livrees, regler EP_TOLE_REELLE_42 (42CrMo4) et EP_TOLE_REELLE_S355 (S355JR) et regenerer les DXF avant decoupe. Chaque decoupe suit la tole qu elle RECOIT : EP_TOLE_REELLE_S355 (8 aujourd hui) pour les encoches a mi-bois et la mortaise de traverse du flanc et les fentes de calage du pied ; EP_TOLE_REELLE_42 (8) pour les encoches et nodes du pied et les rainures des patins.
- **Entretoises** : E235+C EN 10305-1, tube de precision 20 x 2 ; 9 coupees a 60 +0,1/0 et 2 a 71,5 +/-0,2, faces dressees // 0,05 : ce sont elles qui fixent l ecart des flancs.

## Pieces fabriquees

| rep | designation | qte | matiere | brut | masse u. | masse tot. | operations |
|---|---|---|---|---|---|---|---|
| 01 | Flanc en treillis | 2 | 42CrMo4 +A | tole 8 mm, cert. 3.1, Re >= 430 | 10.24 kg | 20.48 kg | decoupe laser, aretes ebavurees (pas de chanfrein), bossages non repris ; encoches a mi-bois et mortaise taillees sur la tole REELLE S355 des pieces qu elles recoivent : mesurer les deux toles livrees, regler EP_TOLE_REELLE_42 (42CrMo4) et EP_TOLE_REELLE_S355 (S355JR) et regenerer les DXF avant decoupe ; graduation de charge gravee (calque GRAVURE) d un seul cote de la lumiere, face gravee montee a l exterieur ; finition : apres decoupe et ebavurage : SABLAGE corindon des deux faces a l identique, pression moderee (planeite), puis BRUNISSAGE noir (oxydation a chaud), aspect mat ; degraisser l huile de sortie de bain, puis film d huile ESTER synthetique haute temperature passe au chiffon et ESSUYE ; ni huile minerale ni silicone ; graduation gravee a 0.2 de profondeur au moins, traits repasses a la peinture blanche haute temperature apres brunissage |
| 03 | Plaque de traverse | 6 | S355JR | tole 8 mm, cert. 2.2 | 0.25 kg | 1.51 kg | DXF = brut : chant du bas + 1 (65 / 39) ; chants du bas FRAISES EN PAQUET serre, paquet aligne sur les faces HAUTES des tenons, a la cote finie 64 / 38, Ra 1,6 : c est le plan de glissement |
| 02b | Plateau de poussoir | 3 | S355JR | tole 8 mm, cert. 2.2 | 0.33 kg | 0.98 kg | 3 plateaux perces : alesage 25,4 traversant ; 2 trous de passage 6,6 decoupes au laser a +/- 38 ; assembles en bloc par 2 vis H M6 x 35, tete en dessous, ecrou au dessus, 8 N.m ; le patin de charge fait fond |
| 02a | Coulisseau a tete inclinee | 1 | S355JR | plat 65 x 40, L 120 (fini 58 x 36,2 x 114) | 1.46 kg | 1.46 kg | dessus a 12 degres sur toute la section ; alesage 25 H8 prof. 20 par dessous ; 4 taraudages M8 prof. 16 dans les faces laterales (avant-trou 6,8 prof. 19), axe a 12 du dessous, x = +/- 44 |
| 06a | Tourillon de centrage | 1 | C45+C | rond etire 25 h9 x 79.5 | 0.31 kg | 0.31 kg | rond etire h9 NON repris : tronconne, chanfrein 1,5 x 45 deg aux deux bouts ; COLLE au fond de l alesage du coulisseau (Loctite 648 (tient 175 C), alesage 25 H8 degraisse) ; centre la pile et coulisse dans le poussoir : 7,9 au repos, 4,3 de garde au dessus du patin a la butee |
| 02c | Coin de commande | 1 | C45 | plat 70 x 45, L 120 (fini 63 x 40 x 114,5) | 1.37 kg | 1.37 kg | acier taraude M16 sur 80 depuis le bout EPAIS, passage 18 au dela ; porte les deux plaques de frottement en bronze entre rebords de 4 : dessus 4,25, dessous 4,43 (faces normales a la pente) |
| 06c | Plaque de frottement, dessus | 1 | CuSn12-C | plat 40 x 8 | 0.20 kg | 0.20 kg | fraisee 38 x 102 x 6, sans trou, faces planes et paralleles a 0,02, Ra 0,8 cote glissement, aretes cassees 0,3 ; entre ses deux rebords sur le dessus du coin, points de silicone HT au montage ; pate graphite haute temperature sur la face qui glisse sous la traverse |
| 06d | Plaque de frottement, dessous | 1 | CuSn12-C | plat 40 x 8 | 0.21 kg | 0.21 kg | comme la haute, mais 38 x 104 x 6 ; entre ses deux rebords sous le coin, points de silicone HT au montage ; pate graphite haute temperature sur la face qui glisse sur la pente du coulisseau |
| 07 | Platine de butee de la vis | 2 | 42CrMo4 +A | tole 8 mm, cert. 3.1, Re >= 430 | 0.45 kg | 0.91 kg | meme tole 42CrMo4 que les flancs (imbriquees dans leurs chutes), empilees et serrees par les deux vis H M10 x 200 de la chape |
| 07b | Entretoise de butee | 2 | E235+C EN 10305-1 | tube de precision 20 x 2 | 0.06 kg | 0.13 kg | coupee a 71,5 +/-0,2, faces dressees ; en compression pure : c est elle qui porte l effort de commande |
| 04a | Patin d'appui rainure | 4 | S355JR | tole 10 mm | 0.13 kg | 0.52 kg | decoupe laser PUIS rainure 9,5 x 1,5 fraisee sur toute la longueur de la face d appui (0,75 de jeu par cote sur la tole reelle du flanc) ; colle en place, cadre monte, sous 0,5 kN de precharge ; un jeu par eprouvette |
| 04b | Patin de charge | 1 | S355JR | tole 10 mm | 0.45 kg | 0.45 kg | sans trou, 58 de long selon x pour laisser passer les tetes des vis du poussoir ; dessus BOMBE R1000 fraise (cylindre d axe transversal, 10 au milieu, 9,58 aux bords) : le poussoir y porte sur une ligne ; dessous plat, colle centre au trace en meme temps que les patins d appui ; un par eprouvette |
| 06b | Entretoise tubulaire | 9 | E235+C EN 10305-1 | tube de precision 20 x 2 | 0.05 kg | 0.48 kg | coupee a 60 +0,1/0, faces dressees // 0,05 : c est elle qui fixe l ecart des flancs ; 7 serrees par vis TH M10 x 100 + ecrou ISO 7042 classe 8, autofreine tout metal, les 2 de la chape par les vis H M10 x 200 |
| 05 | Pied a mi-bois | 4 | S355JR | tole 8 mm, cert. 2.2 | 0.87 kg | 3.49 kg | ajoure, bossages aux deux bouts qui posent sur les crochets d etuve, fente de calage 8,4 x 7 a 5 du bout ; encoches et nodes taillees sur la tole REELLE du flanc (42CrMo4), fente sur celle du crochet (S355) : mesurer les deux toles livrees, regler EP_TOLE_REELLE_42 (42CrMo4) et EP_TOLE_REELLE_S355 (S355JR) et regenerer les DXF avant decoupe ; meme plaque pour les deux positions : 2 dans le chant bas (couche), 2 aux coins de l about a 38 degres (debout), aretes de pose a 447 |
| 05c | Crochet d etuve | 4 | S355JR | tole 8 mm, cert. 2.2 | 0.17 kg | 0.69 kg | cadre DEBOUT : pend par 4 langues a bec dans la colonne de trous carres de 10 (paroi 1), dans le plan des flancs ; l arete du pied en V pose sur son appui, calee par la dent dans la fente du pied. Le fond de l etuve ne porte rien ; dent a 47,2 de la paroi pour une etuve de 538 |

## Pieces du commerce

| rep | designation | qte | reference | matiere | masse u. | remarque |
|---|---|---|---|---|---|---|
| 02f | Vis de guidage CHC M8 x 12 | 4 | CHC M8 x 12 ISO 4762 8.8, tete lisse (non moletee) | 8.8 | 0.01 kg | piece du commerce ; 12 sous tete, toute la tige dans le taraudage de 16 ; c est la TETE (13 x 8) qui guide : cylindre sur plan, contact lineique |
| 02d | Vis de commande H M16 x 160 | 1 | vis H M16 x 160 ISO 4017 8.8 brute, filetee jusqu a la tete | 8.8 | 0.34 kg | piece du commerce, filetee jusqu a la tete, montee a la pate cuivre ; tete de 10 (douille de 24) sur la butee ; ecrous et butee figures : ils montrent l arret axial dans les deux sens |
| 04c | Plat de renfort colle | 2 | feuillard 20 x 2 S235, coupe a 840 | S235 | 0.26 kg | piece du commerce, coupee a longueur, bavures retirees ; collee sur toute la longueur a y = +/- 34, poncer et degraisser les deux faces ; un jeu par eprouvette |
| 02e | Pile de 12 rondelles Belleville | 1 | 12 rondelles EN 16983 A50 | 51CrV4 (1.8159) | 0.41 kg | piece du commerce : 12 rondelles 50 x 25,4 x 3 (ex-DIN 2093, PAS en C60S) montees TETE-BECHE, grand diametre aux deux bouts ; 18,5 kN a plat, course 15,6 mm ; cales de rattrapage 1 et 2 mm (50 / 26) entre poussoir et pile si l empilement est court |

**Masse du cadre complet : 34.5 kg.** Poutrelle beton : 22.2 kg. Masses du modele 3D (out/masses.json du 09/10/2026).

## Visserie et petites pieces du commerce

| rep | designation | qte | remarque |
|---|---|---|---|
| V1 | Vis TH M10 x 100 ISO 4017 8.8 zinguee (filetage total) + ecrou ISO 7042 classe 8, autofreine tout metal + 2 rondelles ISO 7089 M10 | 7 | entretoises de cadre : 4 de coin, 2 de bielle, 1 de sommet. Serrage 80, filetage total : la vis depasse de l ecrou de 10 ; 25 N.m. Pas d ecrou a bague polyamide (ISO 7040, DIN 985) : elle ne freine plus a 150 C. Acier, pas inox : meme dilatation que les flancs, la precharge tient a chaud |
| V2 | Vis TH M10 x 100 ISO 4017 8.8 zinguee (filetage total) + ecrou ISO 7042 classe 8, autofreine tout metal + 2 rondelles ISO 7089 M10 : MEME ARTICLE QUE V1 | 2 | paquet de plaques de traverse, a y = +/- 17 : les deux vis tiennent les plaques alignees pour dresser le chant en paquet ; elles ne reprennent aucune charge. Serrage 52, la vis depasse de l ecrou de 38, entre les flancs ; 25 N.m |
| V3 | Vis H M6 x 35 ISO 4017 8.8 zinguee + rondelle ISO 7089 M6 + ecrou ISO 7042 M6 classe 8 tout metal | 2 | serrent les 3 plateaux du poussoir en un bloc, dans les trous de 6,6 a +/- 38 : TETE EN DESSOUS, rondelle et ecrou au dessus, a cote de la pile. Sous le plateau bas il n y a que les 10 du patin de charge jusqu a la poutrelle : une tete de 4 y tient (6 de garde), un ecrou non. Serrage modere, 8 N.m ; la vis depasse de l ecrou de 3,4 ; restent sur le poussoir |
| V4 | Cale de rattrapage D50 / D26, feuillard acier, ep. 1 et 2 mm | 2 | une de chaque, entre le poussoir et la pile, si l empilement mesure au montage est court : le coin doit toucher a moins de 5 mm de son repos |
| V5 | Rondelle trempee AS 1730 (17 x 30 x 1) | 2 | cote interieur des platines, sous les ecrous V7 : deux empilees font les 2 mm de rondelle trempee (une rondelle trempee 30 x 2 n existe pas en M16) |
| V6 | Rondelle trempee AS 1730 (17 x 30 x 1) : MEME ARTICLE QUE V5 | 2 | sous la tete de la vis de commande, face EXTERIEURE des platines : elles encaissent les 5.5 kN de commande ; pate graphite haute temperature entre elles, la tete tourne dessus |
| V7 | Ecrou M16 HM ISO 4035 | 2 | bloques l un sur l autre cote interieur des platines, sur les rondelles V5, avec 0,1 a 0,3 de jeu axial : ils ne retiennent la vis qu au desserrage, 329 N |
| V8 | Vis H M10 x 200 ISO 4014 8.8 zinguee (filetee sur 32) + 2 ecrous H M10 ISO 4032 classe 8 + 5 rondelles ISO 7089 M10 | 2 | vis de chape : tete et 1 rondelle derriere le flanc oppose, flanc, entretoise de cadre, flanc, entretoise de butee, platines, 4 rondelles, ecrou serre puis contre-ecrou bloque contre lui. Serrage 173,5, filet a partir de 168 : le premier ecrou y tombe avec 5,5 de marge, la vis depasse du contre-ecrou de 9,7 ; 25 N.m sur le premier |

## Pieces planes a decouper

Fichiers DXF dans `out/dxf/`, cotes en millimetres, contours fermes, indice B du 05/10/2026 ; la liste tenue a jour par `export_dxf.py` est `out/dxf/LISTE.txt`.

- **Calques** : DECOUPE = contour a couper ; GRAVURE = marquage laser, sans traverser, sur la face superieure de decoupe (graduation de charge du flanc, d un seul cote de la lumiere : face gravee montee a l exterieur) ; TEXTE = identification, ni coupe ni marquage.
- **Toles reelles** : mesurer les deux toles livrees, regler EP_TOLE_REELLE_42 (42CrMo4) et EP_TOLE_REELLE_S355 (S355JR) et regenerer les DXF avant decoupe. Le texte de chaque DXF cite l epaisseur pour laquelle ses fentes et encoches ont ete taillees.
- **Brut de decoupe** : le DXF de la traverse porte 1 mm de surepaisseur sur le chant du bas (fraise ensuite en paquet).
- **Groupes** : `tole_<ep>mm_<nuance>.dxf` reprend tous les exemplaires d une epaisseur et d une nuance, ranges en etageres de 3000 mm de large au plus. C est un controle de quantites, pas une imbrication : le decoupeur imbrique sur son format. Les pieces en attente sont dans un groupe a part, suffixe `_EN_ATTENTE`.
- Les pieces du commerce n ont pas de DXF.

| fichier | epaisseur | matiere | nombre | statut |
|---|---|---|---|---|
| flanc.dxf | 8 mm | 42CrMo4 +A | 2 | a decouper |
| traverse.dxf | 8 mm | S355JR | 6 | a decouper ; DXF = brut, reprise apres decoupe |
| poussoir.dxf | 8 mm | S355JR | 3 | a decouper |
| support.dxf | 8 mm | 42CrMo4 +A | 2 | a decouper |
| patin_appui.dxf | 10 mm | S355JR | 4 | a decouper |
| patin_charge.dxf | 10 mm | S355JR | 1 | a decouper |
| pied.dxf | 8 mm | S355JR | 4 | a decouper |
| crochet.dxf | 8 mm | S355JR | 4 | a decouper |
| tole_8mm_42crmo4.dxf | 8 mm | 42CrMo4 +A | 4 | groupe : flanc, support |
| tole_8mm_s355.dxf | 8 mm | S355JR | 17 | groupe : traverse, poussoir, pied, crochet |
| tole_10mm_s355.dxf | 10 mm | S355JR | 5 | groupe : patin_appui, patin_charge |

## Reglages et constantes d'essai

| grandeur | valeur |
|---|---|
| Portee entre bossages | 750 mm |
| Bossages | R150, balancier, 339 MPa de Hertz sur 6,4 mm portants |
| Pression de Hertz aux appuis | 339 MPa ; limite 480 MPa, 1,6 Re a chaud du patin S355JR, le plus mou des deux corps ; coefficient 1.42 |
| Pile Belleville | 12 x EN 16983 A50 en 51CrV4 (1.8159), hauteur libre 51.6 mm |
| Effort de la pile a plat | 18.5 kN |
| Course totale de la pile | 15.6 mm |
| Ecrasement a 12 kN | 9.65 mm, soit 1243 N/mm en secant |
| Butee de course (bas de lumiere) | 11.8 mm, plafonne l'effort a 14.4 kN |
| Rattrapage d empilement | 2.4 mm en reserve au dela des 12 kN ; cales V4 de 1 et 2 mm |
| Commande | coin acier a 12 degres, vis M16 normale aux flancs |
| Course par tour | 0.425 mm de coulisseau, environ 549 N |
| Precharge de collage, 0,5 kN | 0.84 tour de vis apres le contact (0.36 mm de pile, 1.7 mm de coin) |
| Couple sur la vis a 12 kN | 14.5 N.m |
| Couple de serrage des vis M10 (V1, V8) | 25 N.m |
| Irreversibilite du filet | helice 2.48 deg / frottement 5.28 deg a mu 0.08 (acier sur acier, pate cuivre), marge x2.13 |
| Coin | autobloquant seulement si mu > 0.106 ; desserrage 329 N a mu 0.12 |
| Flancs du filet, taraude dans l acier | 9.2 MPa pour 12 admis, 80 mm filetes, engagement utile 24 mm |
| Plaques de frottement | usinees en CuSn12-C, 38 x 102 (dessus) et 38 x 104 (dessous) x 6 ; pate graphite haute temperature ; 7.6 MPa au plus pour 25 admis |
| Rebords des plaquettes | 4.25 (dessus) et 4.43 (dessous) x 4, 23.9 MPa de flexion, garde 2 sous le bronze |
| Portee de la plaquette haute | 30.0 x 52.8 mm (sur 60) en fin de course, 7.6 MPa |
| Portee de la plaquette basse | 38.0 x 50.4 mm (sur 58) en fin de course, 6.3 MPa |
| Aretes des pieces de tole | ebavurees, sans chanfrein ; les calculs comptent 0.8 non portant a chaque bord |
| Effort estime a la fissuration (beton a 4 MPa) | 5.1 kN |
| Fleche a la fissuration | 0.12 mm |
| Jauge fibre sur la membrure haute | 18.8 microdef/kN |
| Calcul EF du flanc a 12 kN | von Mises 213 MPa, coefficient 2.02 a froid, fleche 0.335 mm |
| Coefficient a 150 C | 1.83 en 42CrMo4 +A de 8 mm (Re 390 a chaud, pour 430 a 20 C EXIGES au certificat) |
| Flambement hors plan des flancs | facteur critique 38.2 couche, 38.3 debout (les deux flancs penchent ensemble, tenus par la flexion des 9 entretoises tubulaires, bouts serres) |
| Flambement, flancs en sens contraire | au moins 31.9 (calcul du 18/09/2026, avant les entretoises de chape et de sommet) |

Graduation de charge gravee sur le flanc, loi non lineaire :

| charge | descente du coulisseau |
|---|---|
| 2 kN | 1.45 mm |
| 4 kN | 2.97 mm |
| 6 kN | 4.55 mm |
| 8 kN | 6.19 mm |
| 10 kN | 7.89 mm |
| 12 kN | 9.65 mm |

## Ordre de montage

Le cadre se monte A PLAT : les entretoises, la traverse et la tete de charge doivent etre en place avant de presenter le second flanc. Les numeros V renvoient a la visserie.

1. **Eprouvette, a l avance.** Coller les deux plats 20 x 2 sous la poutrelle, a y = +/- 34 (axe des flancs), sur toute la longueur ; poncer P80 et degraisser les deux faces ; polymeriser.
2. **Coin, a l avance.** Degraisser les deux sieges ; poser chaque plaque de frottement ENTRE SES DEUX REBORDS (la plus longue, 104, dessous), quelques points de silicone haute temperature sur le siege degraisse -- PAS d epoxy, bronze et acier ne se dilatent pas pareil ; laisser prendre. PUIS seulement, pate graphite haute temperature sur les faces de glissement, rien sur les sieges : le silicone ne prend pas sur une pate.
3. **Poussoir, a l avance.** Empiler les 3 plateaux, alesages alignes sur un rond de 25 ; passer les deux vis V3 PAR DESSOUS (tete sous le plateau bas), rondelle et ecrou au dessus, serrer a 8 N.m. Le poussoir est desormais un bloc ; il sert a toutes les eprouvettes.
4. **Sous-ensemble de chape, sur l etabli.** Sur la vis H M16 x 160 (02d), enfiler sous la tete les deux rondelles AS (V6), pate graphite entre elles, les deux platines, les deux rondelles trempees (V5), puis visser les deux ecrous HM (V7) : 0,1 a 0,3 mm de jeu axial, contre-bloquer. Pate cuivre sur le filet de la vis.
5. **Empilement.** Mesurer la poutrelle avec ses plats, les patins d appui sous la rainure, le patin de charge, le poussoir et la pile libre. Du sommet des bossages au dessous du coulisseau, le nominal fait 203,1 (8,5 + 2 + 107 + 10 + 24 + 51,6). S il manque plus de 1 mm, prevoir entre poussoir et pile la cale de 1, de 2 ou les deux (V4) : au dela des 12 kN le coin ne garde que 2,4 mm de reserve en hauteur.
6. **Premier flanc.** Poser a plat, sur cales de 20, le flanc OPPOSE a la chape, face gravee DESSOUS : la graduation doit finir a l exterieur. Passer par dessous, rondelle sous tete, les 7 vis V1 (4 de coin, 2 de bielle, 1 de sommet) et les 2 vis V8 (chape, x = +/- 52). Enfiler une entretoise de 60 sur chacune des 9 vis.
7. **Traverse.** Engager dans la mortaise le paquet des 6 plaques, serre par les deux vis V2 (rondelle sous tete et sous ecrou ISO 7042, 25 N.m) ; chants dresses du cote du coin.
8. **Poutrelle.** La coucher dans la fenetre du flanc, plats vers les bossages, SANS ses patins d appui, sur cales de 6,5 sous sa face laterale (elle descend de 13,5 sous le flanc).
9. **Tete de charge.** Encoller le patin de charge sur sa face inferieure et le poser au milieu de la poutrelle, centre au trace, bombe vers la tete ; poser dessus le poussoir visse (3 plateaux), tetes de vis en bas de part et d autre du patin ; poser la cale eventuelle (V4), la pile TETE-BECHE (grand diametre aux deux bouts) puis le coulisseau, tourillon colle dessous a l avance (Loctite 648 dans l alesage degraisse, polymeriser avant montage), cote epais de sa pente vers la chape. De cet encollage a la precharge, tout doit tenir dans la vie en pot de la colle : faire d abord les etapes 2 a 5 et preparer la visserie. Si elle est trop courte, coller le patin de charge la veille sur la poutrelle, centre au trace, sous une masse.
10. **Second flanc.** Le presenter face gravee DESSUS : il enfile les 9 vis, les tenons de la traverse et la poutrelle dans sa fenetre. Poser les 7 ecrous V1 sur rondelle, serres sans bloquer.
11. **Chape.** Enfiler sur les deux vis V8 les entretoises de butee de 71,5, puis le sous-ensemble de chape, la vis passant par la fente du coin ; 4 rondelles et un ecrou H par vis, 25 N.m, puis le contre-ecrou H bloque contre lui en tenant le premier.
12. **Pieds.** Dresser le cadre et le poser dans ses deux pieds couches, encoche dans encoche : les nodes serrent de 0,1 par cote, chasser au maillet. Bloquer les V1 a 25 N.m. La poutrelle, sans patins, repose sur les bossages.
13. **Patins d appui, coin non engage.** Soulever la poutrelle d environ 9,5 mm, glisser les 4 patins par la fenetre, rainure SECHE sur le bossage (c est un balancier, il doit basculer) et colle sur la face superieure seulement, contre le plat ; reposer.
14. **Guides.** Visser les 4 CHC M8 x 12 au travers des lumieres dans les taraudages du coulisseau. C est la TETE qui guide : jamais de vis a tete fraisee.
15. **Coin.** Pate cuivre dans son taraudage ; l engager du cote des tetes de V8, bout MINCE en premier, par la fente du flanc, entre la traverse et le coulisseau ; visser la vis jusqu au contact. Le bout epais doit alors etre a moins de 5 mm de sa position de repos, 47,5 mm hors de la face exterieure du flanc ; sinon revoir les cales (etape 5).
16. **Precharge.** 0,84 tour de vis au dela du contact (0,36 mm de pile, 1,7 mm de coin) donne 0,5 kN. Laisser polymeriser sous cette precharge : l epoxy rattrape l hyperstaticite des quatre appuis. Post-cuire selon la notice Duralco avant toute mise en charge.
17. **Etalonnage.** Etalonner la graduation de charge sur presse, ou par la fibre de la membrure.

## Position debout, dans l'etuve

1. Accrocher d abord les 4 crochets aux parois de l etuve : crochet a l horizontale, engager les trois tetes de langue DE FACE dans leurs trous carres, puis laisser descendre : les becs retombent derriere la paroi.
2. Le cadre couche sur ses pieds, engager les deux pieds en V UN PAR UN sur les deux coins d un meme about, chacun chasse le long de sa propre encoche a 38 degres (maillet, nodes). Ils ne se montent pas ensemble : leurs encoches font 76 degres entre elles.
3. Soulever le cadre hors des pieds couches, qui restent sur la paillasse, et le dresser sur ses pieds en V.
4. L entrer dans l etuve vis vers la porte, pieds tenus 5 mm au dessus des appuis jusqu au fond, puis descendre les quatre fentes des pieds sur les dents des crochets.
5. Calage de la poutrelle debout : point ouvert, assume (voir `DEBOUT.md`, paragraphe 6).

## Changement d'eprouvette

Les plats, les patins d appui et le patin de charge sont colles sur la poutrelle et partent avec elle : il faut un jeu neuf par eprouvette (4 patins d appui, 1 patin de charge, 2 plats ; colle). Le poussoir visse porte sur le patin de charge, centre par le tourillon, et la tete ne peut remonter que de 11 avant que le coulisseau touche les entretoises de chape : l eprouvette ne sort pas cadre ferme, on rouvre le flanc cote chape.

1. Decharger : devisser la vis jusqu a liberer la pile, puis jusqu a degager le filet ; sortir le coin du cote des tetes de V8.
2. Deposer les 4 guides. Sortir le cadre de l etuve ou de ses pieds et le coucher a plat, chape en haut, sur cales de 20.
3. Deposer les ecrous et rondelles des deux V8, le sous-ensemble de chape d un bloc (platines et vis), puis les deux entretoises de butee.
4. Deposer les 7 ecrous V1 et soulever le flanc cote chape.
5. Sortir l eprouvette avec sa tete de charge ; sur l etabli, soulever le poussoir visse, qui resservira tel quel : le patin de charge reste colle sur la poutrelle.
6. Remonter la nouvelle eprouvette, preparee aux etapes 1 et 5 de l ordre de montage, en reprenant a l etape 8 : le premier flanc a garde ses vis, ses entretoises et la traverse.

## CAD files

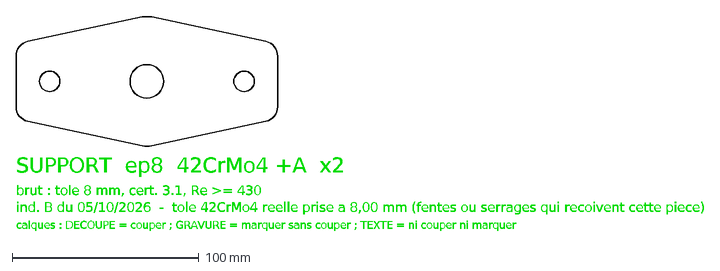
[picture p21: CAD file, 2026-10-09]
out/dxf/support.dxf
SUPPORT ep8 42CrMo4 +A x2
brut : tole 8 mm, cert. 3.1, Re >= 430
ind. B du 05/10/2026 - tole 42CrMo4 reelle prise a 8,00 mm (fentes ou serrages qui recoivent cette piece)
calques : DECOUPE = couper ; GRAVURE = marquer sans couper ; TEXTE = ni couper ni marquer

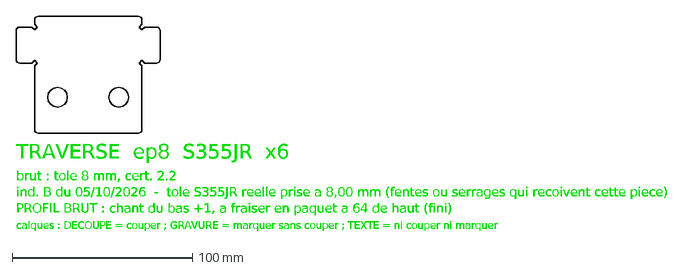
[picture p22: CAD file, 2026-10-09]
out/dxf/traverse.dxf
TRAVERSE ep8 S355JR x6
brut : tole 8 mm, cert. 2.2
ind. B du 05/10/2026 - tole S355JR reelle prise a 8,00 mm (fentes ou serrages qui recoivent cette piece)
PROFIL BRUT : chant du bas +1, a fraiser en paquet a 64 de haut (fini)
calques : DECOUPE = couper ; GRAVURE = marquer sans couper ; TEXTE = ni couper ni marquer

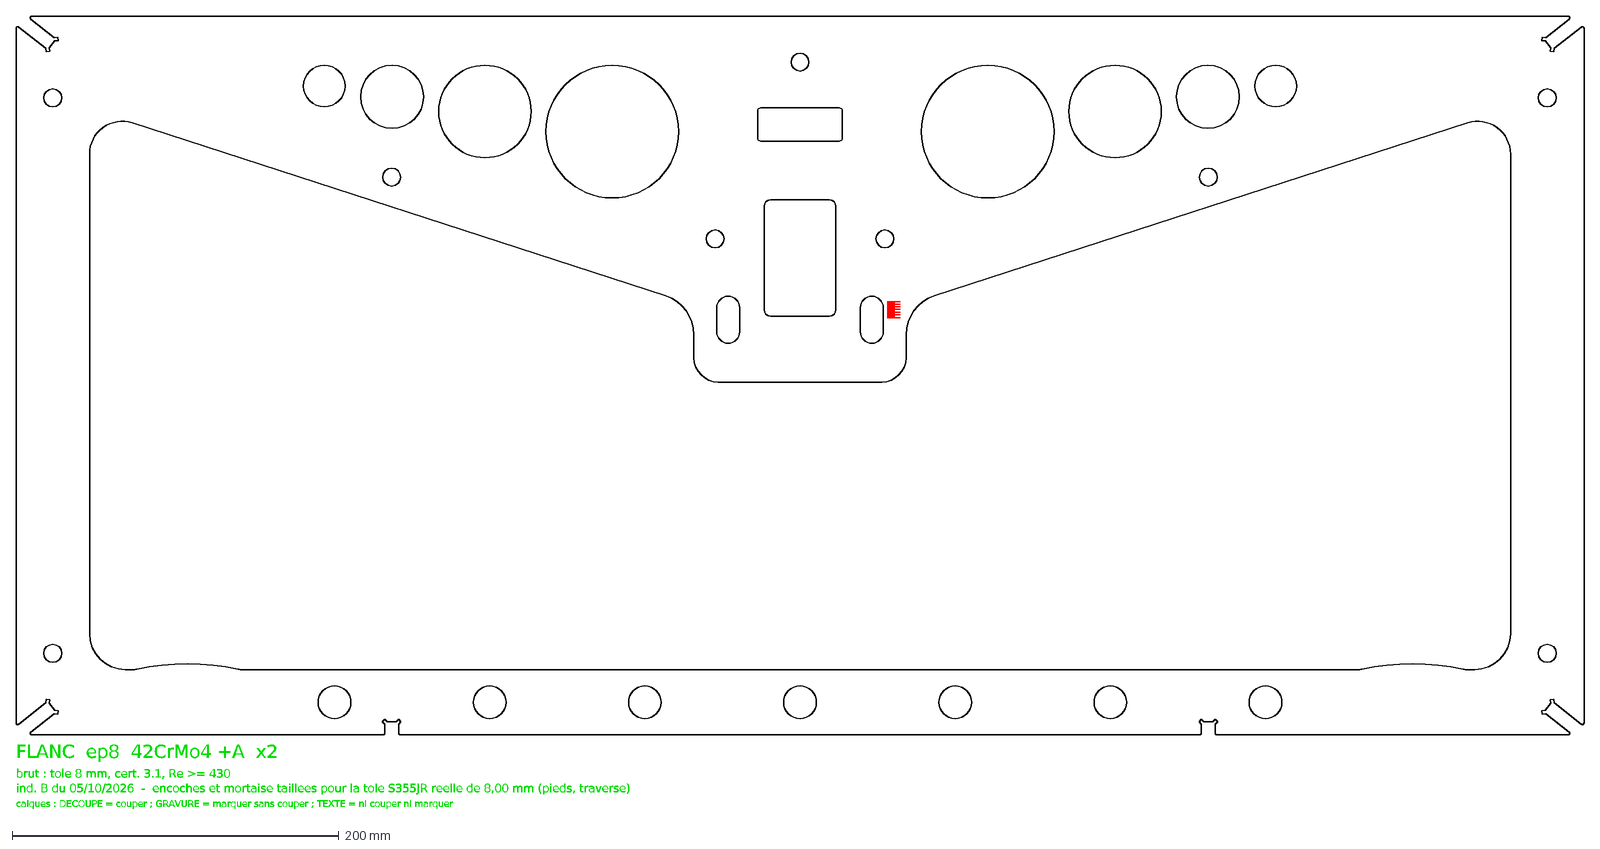
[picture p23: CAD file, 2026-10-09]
out/dxf/flanc.dxf
FLANC ep8 42CrMo4 +A x2
brut : tole 8 mm, cert. 3.1, Re >= 430
ind. B du 05/10/2026 - encoches et mortaise taillees pour la tole S355JR reelle de 8,00 mm (pieds, traverse)
calques : DECOUPE = couper ; GRAVURE = marquer sans couper ; TEXTE = ni couper ni marquer

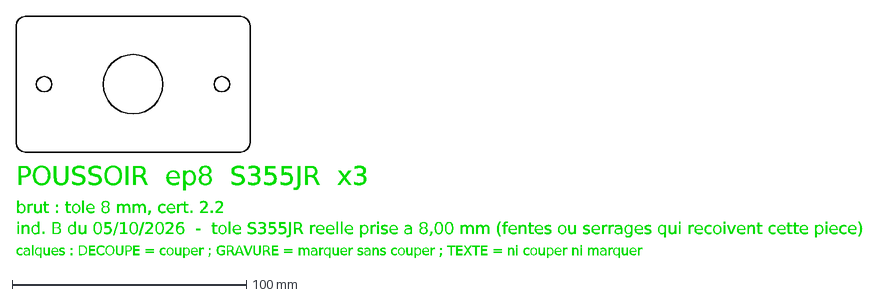
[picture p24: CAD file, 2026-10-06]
out/dxf/poussoir.dxf
POUSSOIR ep8 S355JR x3
brut : tole 8 mm, cert. 2.2
ind. B du 05/10/2026 - tole S355JR reelle prise a 8,00 mm (fentes ou serrages qui recoivent cette piece)
calques : DECOUPE = couper ; GRAVURE = marquer sans couper ; TEXTE = ni couper ni marquer

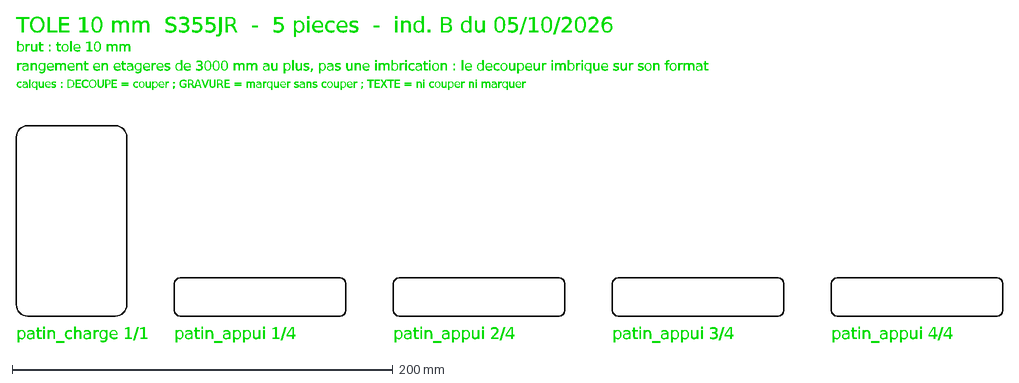
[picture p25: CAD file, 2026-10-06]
out/dxf/tole_10mm_s355.dxf
patin_charge 1/1
patin_appui 1/4
patin_appui 2/4
patin_appui 3/4
patin_appui 4/4
calques : DECOUPE = couper ; GRAVURE = marquer sans couper ; TEXTE = ni couper ni marquer
rangement en etageres de 3000 mm au plus, pas une imbrication : le decoupeur imbrique sur son format
brut : tole 10 mm
TOLE 10 mm S355JR - 5 pieces - ind. B du 05/10/2026

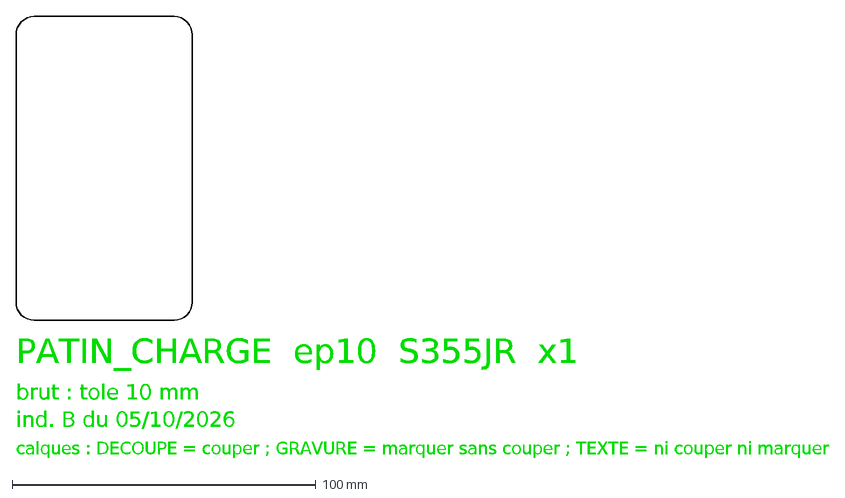
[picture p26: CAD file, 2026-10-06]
out/dxf/patin_charge.dxf
PATIN_CHARGE ep10 S355JR x1
brut : tole 10 mm
ind. B du 05/10/2026
calques : DECOUPE = couper ; GRAVURE = marquer sans couper ; TEXTE = ni couper ni marquer

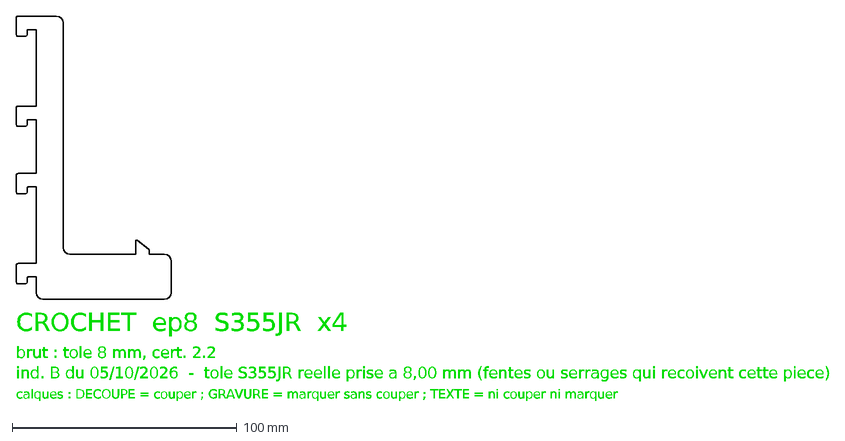
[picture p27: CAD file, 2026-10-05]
out/dxf/crochet.dxf
CROCHET ep8 S355JR x4
brut : tole 8 mm, cert. 2.2
ind. B du 05/10/2026 - tole S355JR reelle prise a 8,00 mm (fentes ou serrages qui recoivent cette piece)
calques : DECOUPE = couper ; GRAVURE = marquer sans couper ; TEXTE = ni couper ni marquer

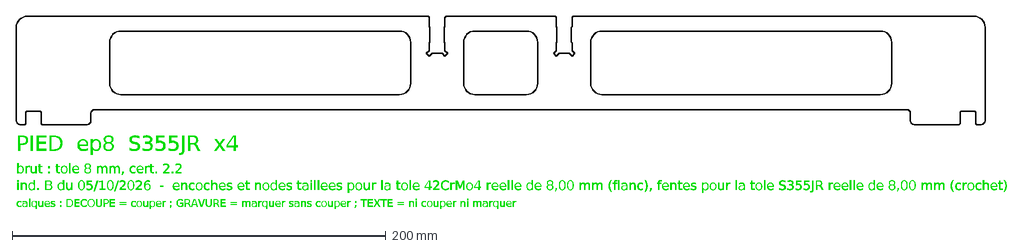
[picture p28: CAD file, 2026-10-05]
out/dxf/pied.dxf
PIED ep8 S355JR x4
brut : tole 8 mm, cert. 2.2
ind. B du 05/10/2026 - encoches et nodes taillees pour la tole 42CrMo4 reelle de 8,00 mm (flanc), fentes pour la tole S355JR reelle de 8,00 mm (crochet)
calques : DECOUPE = couper ; GRAVURE = marquer sans couper ; TEXTE = ni couper ni marquer

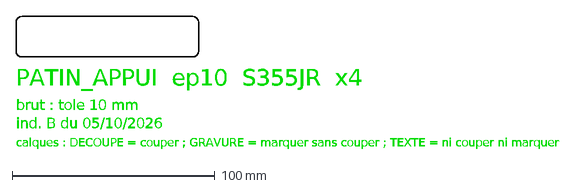
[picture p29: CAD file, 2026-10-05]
out/dxf/patin_appui.dxf
PATIN_APPUI ep10 S355JR x4
brut : tole 10 mm
ind. B du 05/10/2026
calques : DECOUPE = couper ; GRAVURE = marquer sans couper ; TEXTE = ni couper ni marquer

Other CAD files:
out/dxf/tole_8mm_42crmo4.dxf
out/dxf/tole_8mm_s355.dxf

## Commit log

2026-10-02 Banc de flexion 3 points, indice A du 02/10/2026
    Modele parametrique (params.py, parts.py), planches A3, DXF de decoupe,
    nomenclature, specification, visionneuse 3D. Etat apres la relecture du
    02/10 et ses corrections ; make.py se termine sans etape en echec.
    Chemins d'outils portables (outils.py) pour une reprise sous Linux,
    note de reprise dans REPRISE.md.
    [crochet.dxf, flanc.dxf, patin_appui.dxf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]
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2026-10-02 Crochet d'etuve accrochable, visserie sur toute la tolerance de tole, ecrous ISO
    - Crochet : langue 6 + bec 3, tete de 9 dans le carre de 10. Un crochet rigide
    a trois langues ne peut s'incliner que de 12,7 deg : la tete de 12 (7 + 5)
    ne passait pas. Pose de face puis descente ; verifie() controle langue + bec.
    - V2 : tige M10 x 90 (80 refusee des 8,34 de tole mesuree). V9 : 4 rondelles
    sous l'ecrou (3 refusees sous 7,75). verifie() passe de 7,25 a 9,2.
    - Ecrous ISO : H M10 ISO 4032 = 8,4 ; tete V7 ISO 4032 + ISO 4035 M16 = 22,8.
    - DXF du crochet, planches 00, 05, 07, NOMENCLATURE, SPEC, DEBOUT regeneres ou
    mis a jour.
    Claude-S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
    [crochet.dxf, tole_8mm_42crmo4_EN_ATTENTE.dxf]
2026-10-02 V9 : contre-ecrou H ISO 4032, freinage tout metal
    Deux ecrous H M10 ISO 4032 contre-bloques au lieu d'un : le premier serre a
    35 N.m, le second est bloque contre lui. Tient a 150 C, comme les ISO 7042 des
    autres vis M10. La M10 x 200 suffit : verifie() compte les deux ecrous et la
    vis depasse du contre-ecrou de 4,9 a 12,7 sur toute la tolerance de tole.
    Planche 07, NOMENCLATURE, SPEC et DEBOUT a jour.
    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
2026-10-05 Reconstruction locale avec FreeCAD apres la session cloud
    Modele 3D, controle d'interference (104 paires, 0 interference, 16 contacts)
    et PDF relances sur le poste, ce que la session cloud ne pouvait pas faire.
    Seules les masses changent, avec le crochet redessine.
2026-10-05 Indice B du 05/10/2026 : etuve de 538, perspective plus fine
    - ETUVE_INTERIEUR 540 -> 538 (marge) : dent du crochet a 47,2 de la paroi,
    degagement de la douille 94 ; verifie() passe, DEBOUT.md a jour.
    - Perspective de la planche 00 : contours apparents des cylindres ajoutes
    (groupe 4 de projectEx) et courbes discretisees a 0,03 au lieu de 0,6.
    - Indice B, date 05/10/2026 dans les cartouches et les DXF.
    - plans.pdf etait ouvert : le PDF de l'indice B est out/plans/plans_indiceB.pdf.
    [crochet.dxf, flanc.dxf, patin_appui.dxf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]
2026-10-05 Etuve de 538 confirmee : pied et crochet bons a decouper
    ETUVE_CONFIRMEE = True : plus d'alerte NE PAS DECOUPER sur les planches,
    les DXF et la nomenclature ; le pied et le crochet rejoignent le DXF de
    groupe 8 mm. Textes de SPEC qui ecrivaient A CONFIRMER en dur rendus
    dependants du drapeau ; DEBOUT, README, REPRISE et SUITE a jour. Seule la
    hauteur de 1400 reste a confirmer. plans.pdf regenere (le PDF provisoire
    plans_indiceB.pdf est retire).
    [crochet.dxf, pied.dxf, tole_8mm_42crmo4.dxf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]
2026-10-05 Crochet d'etuve : 4 griffes au pas 40 / 30 / 40, la plus basse a 10 du bas
    - ETUVE_TROU_PAS corrige : 40 et 30 en alternance (avant 40 / 50).
    - CROCHET_N_LANGUES = 4 : un trou de plus porte, hauteur inchangee (126).
    - CROCHET_GARDE_BAS = 10 : la langue basse descend au niveau de l'appui
    (avant 30 sous elle) ; bras de levier du controle de paroi recalcule.
    - DEBOUT.md a jour ; make.py : 0 etape en echec, 0 interference.
    [crochet.dxf, tole_8mm_42crmo4.dxf]
2026-10-05 Pieds : fentes des crochets a 500 d'entraxe, pied de 518,4
    PIED_Y derive de PIED_FENTE_ENTRAXE = 500 (colonnes de trous de l'etuve),
    de la fente (tole + 0,4) et de 5 de bord : 518,4, soit 9,8 de jeu de chaque
    cote dans l'etuve de 538. Controle de l'entraxe dans verifie(), cote 500 sur
    la planche 05, textes a jour (params, DEBOUT, SPEC).
    [pied.dxf, tole_8mm_42crmo4.dxf]
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2026-10-05 Deux nuances de tole de 8, nomenclature Excel
    - Flancs et platines de butee en 42CrMo4 +A (cert. 3.1, Re >= 430) ;
    pieds, crochets, plaques de traverse et plateaux du poussoir en S355JR.
    - Deux epaisseurs reelles a mesurer (EP_TOLE_REELLE_42, _S355) : chaque
    fente, encoche ou mortaise suit la tole qu'elle recoit. Geometrie
    identique a 1e-9 avec les valeurs par defaut ; controles de verifie() sur
    le Re de la nuance de chaque piece.
    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
    [NOMENCLATURE.xlsx, crochet.dxf, flanc.dxf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]
2026-10-05 Entretoises en tube 20 x 2, serrage des M10 a 25 N.m
    - ENTRETOISE_DI 11 -> 16 (cadre et chape) ; COUPLE_M10 = 25 N.m et K_COUPLE
    passent dans params.py, precharge 12,5 kN, soit 111 MPa dans le tube.
    - verifie() controle la precharge contre le Re du tube a chaud (190 / 1,5).
    - Voilement recalcule (fem_flamb3) : 38,2 couche, 38,3 debout (39,0 / 39,1
    avec le 20 x 4,5). Compression des entretoises de chape : 24,5 MPa.
    - DEBOUT, README, REPRISE a jour ; make.py : 0 etape en echec.
    [NOMENCLATURE.xlsx]
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2026-10-06 Patin de charge bombe R1000 : vraie flexion 3 points
    Dessus du patin de charge en cylindre d'axe transversal, R1000, sommet au
    milieu (1,25 de chute aux bords) ; dessous plat, toujours colle. Le plateau
    bas du poussoir y porte sur une ligne : Hertz 88 MPa a 12 kN, coefficient
    5,4, controle dans verifie(). Vue de face cotee sur la planche 04, note de
    fabrication, SPEC (bombe et alignement du poussoir par les goupilles).
    [NOMENCLATURE.xlsx]
2026-10-06 Poussoir visse en bloc, patin de charge raccourci a 58 sans trou
    - Les 3 plateaux sont tenus par 2 vis H M6 x 35 (tete dessous, 6 de garde
    a la poutrelle) + rondelle + ecrou ISO 7042 dessus, a x = +/- 38 (trous
    laser 6,6) ; les goupilles 8 m6 et les trous 8 H7 du patin disparaissent.
    - Patin de charge 58 x 100 (longueur derivee des tetes de vis), sans trou,
    bombe R1000 (9,58 aux bords) ; 2,07 MPa sur le beton.
    - Le poussoir est centre par le tourillon, le patin colle au trace.
    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
    [NOMENCLATURE.xlsx, patin_charge.dxf, poussoir.dxf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]
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2026-10-07 Plaquettes du coin usinees en CuSn12 : 38 x 102 et 38 x 104 x 5, sans trou
    [NOMENCLATURE.xlsx]
2026-10-07 Commande : vis H M16 x 160 ISO 4017 filetage total au lieu de la tige et des ecrous de tete
    Visserie renumerotee : V8 -> V7, V9 -> V8.
    [NOMENCLATURE.xlsx]
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2026-10-07 Paquet de traverse : deux vis H M10 x 80 filetage total au lieu d'une tige filetee
    [NOMENCLATURE.xlsx, tole_8mm_s355.dxf, traverse.dxf]
2026-10-07 V1 et V2 : meme vis TH M10 x 100 ISO 4017 a filetage total
    [NOMENCLATURE.xlsx]
2026-10-08 Butee de la vis de commande : 2 rondelles AS 1730 graissees au lieu de la butee a aiguilles
    Couple de manoeuvre 14,5 N.m (frottement sous tete compte).
    [NOMENCLATURE.xlsx]
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2026-10-09 Conges interieurs R2 minimum partout (controle automatique), un PDF par feuille
    Coin : rebords de 4 sous conge R2, plaquettes 38 x 102/104 x 6, jeu 2 par bout.
    Pied : fond des fentes de calage a degagements R2. Crochet : fond de gorge R2.
    [NOMENCLATURE.xlsx, crochet.dxf, flanc.dxf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]
2026-10-09 R2 mini seulement sur les pieces fraisees : pieds et crochets revenus a leurs conges laser
    [NOMENCLATURE.xlsx, crochet.dxf, pied.dxf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]
2026-10-09 Toles sans chanfrein au modele 3D ni sur les plans : aretes ebavurees
    Les calculs gardent 0,8 non portant a chaque bord par prudence.
    [NOMENCLATURE.xlsx]
2026-10-19 Plaquettes de bronze 41 de large (guident le coin dans la fente), encochees sur des tenons, fixees par 2 CHC M4 dans des oblongs
    Coin : tenons 24 x 8 x 4 au milieu des bouts, conges R2 au pied, 4 taraudages M4.
    Fente du coin dans les flancs ramenee a 42,2 (0,6 de jeu par cote du bronze).
    Silicone supprime ; nouvelle visserie V9.
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2026-10-20 Plaquettes 133 / 136 : engagees sur toute l'epaisseur des deux flancs ; visionneuse 3D avec course du coin
    Les branches des plaquettes passent de part et d'autre des ecrous V7 (controle
    corrige). Visionneuse : curseur de course, coulisseau, pile ecrasee, effort, butee.
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
